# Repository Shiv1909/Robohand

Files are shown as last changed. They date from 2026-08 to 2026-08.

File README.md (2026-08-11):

# Robohand — DIY Fingerbot

A voice-controlled robot finger that physically presses a wall switch on command.
Say *"Hey Siri, turn on the fan"* and a servo swings an arm into the switch.

The homemade version of a commercial SwitchBot Bot — built as a first hands-on
robotics / embedded project, and aiming to beat the commercial one on a specific
axis: **density**. A SwitchBot is 43 × 37 mm and physically cannot fit two adjacent
switches on a 22 mm-pitch Indian modular board. An MG90S can.

**Coming back to this after a break? Start with [STATUS.md](STATUS.md)** — current
state, what's blocked, what to do next, and every decision already settled.

## Status

**"Hey Siri, turn on Fingerbot" swings the arm.** Working on real hardware as of
2026-08-11 — the firmware side is essentially done, and what's left is mechanical.

| Phase | State |
| --- | --- |
| 0 — Simulation | ✅ done (Arduino Uno, in Wokwi) |
| 1 — Servo moves on real hardware | ✅ **validated 2026-08-11** |
| 1b — Debounced button trigger | ✅ **validated 2026-08-11** — 14 pushes, 14 presses |
| 1c — Two-position on/off toggle | ✅ **validated 2026-08-11** — strict ON/OFF alternation |
| 1d — Serial calibration console | firmware written + compiling + unit-tested, **not yet flashed** |
| 2 — WiFi trigger | ⏭️ skipped — HomeSpan subsumes it |
| 3 — Siri / Apple Home | ✅ **validated 2026-08-11** — paired with Apple Home, Siri drives the servo |
| 4 — 3D-printed arm and mount | blocked on switch measurements |
| 5 — Permanent install | not started |

## Hardware

ESP32 + MG90S metal-gear servo, driven from a **separate 5 V supply** with a common
ground. Full parts list with links and prices: **[BOM.md](BOM.md)**.

## Quick start

```bash
# compile
pio run -e phase1_autopress          # servo presses every 3s, no inputs
pio run -e phase1b_button            # servo presses on a debounced button
pio run -e phase1c_toggle            # button toggles between on/off angles
pio run -e phase1d_calibrate         # serial console for finding the angles
pio run -e phase3_homekit            # Siri / Apple Home (needs include/secrets.h)

# run logic tests on your PC — no ESP32 needed (41 tests)
pio test -e native

# flash
pio run -e phase1_autopress -t upload
```

Always pass `-e`. A bare `pio run` builds only the default environment and silently
skips the other.

**Before wiring anything, read [WIRING.md](WIRING.md).** It has the layout and a
pre-flight checklist — reversed polarity on the servo supply will kill the ESP32.

## Repo layout

```
src/phase1_autopress.cpp    Phase 1 firmware. Known-good baseline; keep it working.
src/phase1b_button.cpp      Phase 1b firmware. Standalone by design.
src/phase1c_toggle.cpp      Phase 1c firmware. Two-position on/off with state.
src/phase1d_calibrate.cpp   Serial console for finding the angles. A tool.
src/phase3_homekit.cpp      Phase 3 firmware. HomeKit accessory driven by Siri.
include/debounce.h          Debounce logic, free of Arduino calls so it unit-tests.
include/switch_state.h      On/off state machine. Idempotent — see below.
include/command_parser.h    Console command parsing + range validation.
include/secrets.h.example   Template for WiFi credentials. Copy to secrets.h.
test/test_debounce/         8 native Unity tests for the debouncer.
test/test_switch_state/     13 native Unity tests for the state machine.
test/test_command_parser/   20 native Unity tests for the parser.
test/wokwi/                 Wokwi scenario (blocked — see project.md).
cad/fingerbot.scad          Parametric OpenSCAD source for the printed parts.
cad/render.ps1              Renders every part to cad/stl/.
cad/stl/                    Ready-to-slice STLs, regenerated by render.ps1.
platformio.ini              Six environments: five firmware, one native test.
project.md                  Plan, phase status, and every gotcha learned so far.
BOM.md                      Parts list, prices, power analysis, measurements.
WIRING.md                   Wiring diagram and first-power-on checklist.
CLAUDE.md                   Toolchain notes for this machine.
```

Each firmware environment compiles exactly one source file, so both can live in
`src/` without their `setup()`/`loop()` colliding. Phase 1 is preserved permanently
as a fallback for isolating hardware faults.

## Things learned the hard way

Full list in [project.md](project.md). The ones that cost the most time:

- **Servo brownout.** An MG90S stalling against a stiff switch browns out the ESP32
  through its onboard regulator. The board reboots at exactly the moment the finger
  pushes hardest — it looks like a code bug and isn't. Separate 5 V supply, common
  ground, bulk capacitor near the servo. *(Verified 2026-08-11: with that wiring,
  22 s of continuous pressing produced no resets.)*
- **No COM port at all ≠ nothing on serial.** The DevKitC's CP2102N needs a Silicon
  Labs driver that Windows Update does not carry. Until it's installed there is no
  port to select, which reads as a dead board. See `WIRING.md`.
- **A 4-pin tactile switch has only two circuits.** Half its leg pairs are
  permanently closed, and the two orientations look identical from outside. **Wire
  it diagonally** — diagonally opposite legs are always one from each pair, so it's
  correct whichever way the switch went in.
- **ESP32Servo needs its PWM timers allocated before `attach()`**, or the servo
  silently never moves.
- **Rockers need two press points.** Press the top for ON, the bottom for OFF. A
  single-point presser can only ever switch one way — solved with a push-pull tether,
  the same approach SwitchBot uses.
- **State changes must be idempotent.** Apple Home re-sends state freely. Actuating
  on a redundant "turn on" would physically press the switch again and turn the light
  *off*. `switch_state.h` returns `Action::None` in that case, and it's unit-tested.
  *(Confirmed in the wild 2026-08-11: HomeKit did exactly this within 100 seconds of
  first pairing, and the arm correctly refused to move.)*
- **Wokwi cannot simulate ESP32 here.** AVR works fine with the same CLI and token;
  ESP32 produces no serial and never executes. Ruled out across both the CLI and the
  VS Code extension. Probably why Phase 0 was done on an Uno.
- **Battery life is set by idle WiFi, not the servo.** The servo is under 2 % of the
  energy budget. Light sleep (not deep sleep) gets ~7.5 mA and makes portable viable.

## License

Personal project, no license granted. Ask if you want to reuse something.

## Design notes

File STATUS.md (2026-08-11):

# STATUS — read this first after a break

Snapshot of the whole project as of **2026-08-11**. Written as a handoff: if you
(or a fresh Claude session) come back cold, start here.

**Everything is committed and pushed** to `main` at
<https://github.com/Shiv1909/Robohand>. Bench photos on the laptop are untracked
and not needed.

---

## Where we are in one line

**Siri works.** "Hey Siri, turn on Fingerbot" swings the arm. Phases 1, 1b, 1c and
**3** are all validated on real hardware (2026-08-11).

The electronics and firmware side of this project is essentially done. What remains
is mechanical: printing an arm, mounting it, and calibrating the angles against the
real switchboard.

| Phase | State |
| --- | --- |
| 0 — Wokwi simulation | ✅ done, on an Arduino Uno |
| 1 — Servo moves | ✅ **validated on hardware 2026-08-11** |
| 1b — Debounced button | ✅ **validated on hardware 2026-08-11**, real switch |
| 1c — Two-position on/off | ✅ **validated on hardware 2026-08-11** |
| 1d — Calibration console | firmware ✅ · 20 tests ✅ · **not flashed** |
| 2 — WiFi trigger | ⏭️ **skipped** — HomeSpan subsumes it |
| 3 — Siri / HomeSpan | ✅ **validated on hardware 2026-08-11** |
| 4 — Printed parts | CAD ✅ rendering · **not printed, not test-fitted** |
| 5 — Permanent install | not started |

**41 native tests pass. 4 firmware environments build clean.**

---

## What the first hardware session actually proved (2026-08-11)

Measured, not assumed:

- **No brownout.** 22 s of continuous auto-pressing, six cycles, and the boot
  banner never reappeared. The 5 V 2 A adapter + 1000 µF near the servo is
  sufficient for one MG90S. This was the project's single biggest risk.
- **Timing is exact.** 0.8 s hold, 3.0 s gap, 3.8 s period — matches
  `phase1_autopress.cpp` to the tenth of a second.
- **The debouncer works against real bounce.** Two separate runs: eight jumper taps
  on GPIO 4 gave eight presses, and fourteen pushes of the real tactile switch gave
  fourteen presses. **No two events closer than 0.9 s in either run** — contact
  bounce settles in single-digit milliseconds, so zero double-fires got through.
  `include/debounce.h` needs no tuning; `DEBOUNCE_MS = 50` is right.
- **The two-position state machine alternates correctly.** Eight presses under
  `phase1c_toggle` gave strict ON/OFF/ON/OFF with no repeats, each move taking
  exactly 0.7 s (`HOLD_MS` 500 + 200 ms settle). `include/switch_state.h` behaves on
  hardware as its 13 tests said it would.
- **The idempotency guard fired for real, within 100 s of the first Siri session.**
  HomeKit sent "turn on" while the switch was already ON, and `requestOn()` returned
  `Action::None` so the arm did not move. With a plain bool it would have pressed an
  already-on rocker and turned the light OFF. This is the single most valuable thing
  `include/switch_state.h` does, it was predicted in that file's header comment
  before any hardware existed, and it is now observed rather than theoretical.
- **Siri and the physical button coexist, sharing one source of truth.** Serial
  caught the sequence that proves it: HomeKit turned the switch ON, then a button
  press turned it **OFF** rather than ON — so `toggle()` read the state Siri had
  set. The button also calls `setVal()` to push its new state up to HomeKit, so
  Apple Home doesn't go stale and the next Siri command isn't silently swallowed.
- **3.3 V PWM drives the MG90S fine.** The logic level converter (item 16919) was
  bought as insurance and is not needed.
- **HomeSpan must be pinned to 1.9.x.** HomeSpan 2.x hard-`#error`s unless the
  arduino-esp32 core is ≥ 3.3.0, and `platform = espressif32 @ 7.0.1` ships 2.0.17.
  Pinned in `platformio.ini`, scoped to the Phase 3 env only — see below.
- **Wire tactile switches diagonally.** Straight across a row gave a permanent
  closed circuit; the same switch worked immediately when rewired diagonally. See
  `WIRING.md` — this cost an hour.

---

## What's actually blocked

1. **Switch measurements not taken.** Blocks final arm length and mount position.
2. **Wokwi can't simulate ESP32** here. Dead end — don't retry, see below.

Nothing else. Phases 1 and 1b are done on hardware.

---

## Next actions, in order

Do these in sequence. Each adds exactly one new thing to debug.

**Everything left is mechanical.** No firmware is blocked.

1. **Measure the switchboard** — rocker height × width, gang pitch, throw. Needs
   only a ruler, and it is the main blocker: it decides arm length and mount
   position for Phase 4.
2. **Print `arm20.stl` in PETG.** Smallest, fastest print, and it tests the least
   certain dimensions in the design — the `horn_*` values are datasheet guesses for
   the stock plastic horn. If they're wrong the arm won't mount at all, so find out
   in 15 minutes rather than after an hour on the cradle. Print it flat, as
   oriented: the bending load then runs *within* the layers rather than across
   them, and it needs no supports.
3. Then `cradle.stl`, also PETG. Test-fit both against the real servo, correct the
   parameter block in `cad/fingerbot.scad`, and re-run `cad\render.ps1`.
4. Mount it on the switchboard with the push-pull tether (see `project.md`, "The
   rocker problem").
5. `pio run -e phase1d_calibrate -t upload` → find the three angles by typing,
   `save`, then paste them into **both** `phase1c_toggle.cpp` and
   `phase3_homekit.cpp`. Needs the printed arm and a real mount first.
6. Then scale: servos 2..N for the other switches on the board.

The angles in `phase1c_toggle.cpp` and `phase3_homekit.cpp` (REST 90, ON 60,
OFF 120) are placeholders. They are *not* calibrated against anything — step 5's
job. Both files carry the same three constants; keep them in step.

---

## Toolchain installed on this machine

All PATH entries are in the **User** environment, so they survive a restart. Open
a **new** terminal after rebooting — and restart VS Code fully, not just its
integrated terminal, since it inherits the PATH of whatever launched it.

| Tool | Version | Location / notes |
| --- | --- | --- |
| PlatformIO Core | 6.1.19 | `~\.platformio`, `penv\Scripts` on User PATH |
| MinGW-w64 GCC | 16.1.0 | winget WinLibs UCRT, on User PATH. **Required for `pio test`** |
| OpenSCAD | 2021.01 | `C:\Program Files\OpenSCAD` — *not* on PATH; `render.ps1` finds it |
| wokwi-cli | 0.26.1 | `%LOCALAPPDATA%\Programs\wokwi-cli`, on User PATH |
| Node / npm | 24.14.0 / 11.9.0 | |
| gh | 2.95.0 | authenticated as `Shiv1909` |
| CP210x VCP driver | Silicon Labs | installed 2026-08-11, `oem186.inf`. **Windows Update does not have it** |

### The ESP32 shows up as COM3

The DevKitC-32E uses a **CP2102N** USB-UART bridge. Windows 11 has no driver for
it and Windows Update will not find one — Device Manager reports
`CM_PROB_FAILED_INSTALL` (Code 28) and **no COM port appears at all**, so
`pio device list` is silently empty. The board is fine; it's just unreachable.

Fixed by installing the Silicon Labs CP210x Universal Windows Driver
(`silabser.inf`) with `pnputil /add-driver ... /install` from an elevated shell.
Already done on this machine; only relevant if it's ever rebuilt.

**Build output lives outside this folder** — `workspace_dir` in `platformio.ini`
sends `.pio` to `%LOCALAPPDATA%\pio-workspace\fingerbot`, because this project
sits in a OneDrive-synced tree. If a `.pio\` folder ever appears next to `src\`,
that redirect got lost.

### Two machine-specific traps

- **Never run `python get-platformio.py`.** Bare `python` here resolves to another
  app's virtualenv (`AppData\Local\hermes\hermes-agent\venv`). Use `py -3.13`.
- **Set a short TEMP before running pio from an agent session.** The scratchpad
  path is ~150 chars and pip/pio blow past Windows' 260-char `MAX_PATH`. The error
  blames antivirus; that's a red herring.
  ```powershell
  $env:TMP = "$env:LOCALAPPDATA\Temp"; $env:TEMP = $env:TMP
  ```

`WOKWI_CLI_TOKEN` is stored in the User environment. **The repo is public — never
commit it.** Remove with:
```powershell
[Environment]::SetEnvironmentVariable("WOKWI_CLI_TOKEN", $null, "User")
```

---

## Decisions already made — don't re-litigate

Each of these cost real time to work out. Full reasoning is in `project.md`.

| Decision | Why |
| --- | --- |
| **Separate 5 V supply, common ground, 1000 µF near the servo** | Stall current browns out the ESP32. Board reboots exactly when the arm pushes hardest — looks like a code bug, isn't |
| **`ESP32PWM::allocateTimer()` before `attach()`** | Otherwise the servo silently never moves |
| **Phase 1 kept as a permanent baseline** | Flash it to prove servo+wiring+power still work before debugging anything else |
| **Phase 2 skipped** | HomeSpan gives phone control *and* Siri from the same code |
| **Phase 3 deferred until 1/1b run on hardware** | One new variable per flash. HomeSpan first would give a dead servo six possible causes instead of one |
| **Rocker needs two press points** | Top = ON, bottom = OFF. Solved with a push-pull tether to an adhesive tab, as SwitchBot does |
| **State changes must be idempotent** | Apple Home re-sends state; acting on a redundant "turn on" would physically turn the light off |
| **Arm 20–25 mm, not 40** | SwitchBot's 8 N target ÷ MG90S's 19.6 N·cm. A 40 mm arm gives only 4.9 N |
| **Wokwi ESP32 is dead here** | AVR works with the same CLI and token; ESP32 never executes. Both CLI and VS Code extension. Probably why Phase 0 used an Uno |
| **Portable IS viable** | ~7.5 mA with WiFi light sleep, not the 80 mA default. ~2 weeks per 18650. Idle radio dominates; the servo is <2 % |
| **6 servos need staggered mounting** | Cradle is 28.1 mm wide, gang pitch ~22 mm. Alternate above/below the rocker line |
| **Don't buy a small board yet** | ESP32-C3 has only 6 PWM channels; Thread would need a C6. A PCA9685 makes the board choice irrelevant |

---

## Open questions for you

- [x] ~~**Is your filament PETG or PLA?**~~ **Both available. Use PETG throughout**
      (decided 2026-08-11), including the throwaway test-fit prints.

      An earlier version of this file said PLA for test-fitting and PETG for the
      final parts. **That was wrong.** PETG prints 0.1–0.3 mm larger than PLA at the
      same nominal size — the same order as the tolerances being checked
      (`horn_blade_t` is 1.9 mm, `horn_hub_d` is 7.4 mm). A PLA fit therefore does
      not predict a PETG fit, so the test would have to be repeated anyway.

      Printing the throwaway part in PETG also means the **PETG printer profile gets
      debugged on a part nobody cares about** — stringing, ooze and bed adhesion are
      problems you have to solve for the real parts regardless.

      PLA is still fine for a pure "does this geometry make sense" sanity check, but
      **any dimension you intend to trust must be measured in PETG.**
- [ ] **Rocker dimensions with a ruler.** The AR measurement said 2 × 7 cm, but the
      photos show a ~1:2 ratio, so the height is probably ~4–4.5 cm.
- [ ] **Gang pitch**, centre-to-centre. Decides how bad the staggering has to be.
- [ ] **Actuation force** (optional — see `BOM.md` for three ways to measure it
      without a proper scale). Not a blocker; printing 20/25/30 mm arms settles it.

---

## Offered but not built

- **CI on GitHub Actions** — would run the 41 tests + 4 builds on every push.
- **Electronics enclosure** — the ESP32 box; DevKitC is 54.4 × 27.9 × 13 mm.
- **A phone app** — recommended against. Apple Home *is* the app.

---

## Document index

| File | What's in it |
| --- | --- |
| `README.md` | Project overview, quick start, repo layout |
| `project.md` | The plan, phase status, every gotcha learned |
| `BOM.md` | Parts list with Robu links, power analysis, measurements |
| `WIRING.md` | Wiring diagram + first-power-on checklist. **Read before connecting anything** |
| `CLAUDE.md` | Toolchain notes for this machine |
| `STATUS.md` | This file |

### Commands worth remembering

```bash
pio run -e phase1_autopress -t upload    # always pass -e; bare `pio run` skips envs
pio test -e native                       # 41 tests, no hardware needed
cd cad; .\render.ps1                     # regenerate STLs + previews
```

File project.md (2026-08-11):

# DIY Fingerbot — Project Brief

A voice-controlled robot finger that presses a physical wall switch on command
("Hey Siri, turn on the fan"). This is the DIY version of a commercial Fingerbot /
SwitchBot Bot, built as a first hands-on robotics + embedded/IoT project.

If you're Claude Code reading this: this file is the handoff from a planning chat.
It has the full plan and current status so you can pick up mid-project.

## What we're building

An ESP32 drives a small servo motor. The servo has a 3D-printed arm that swings to
press a switch, holds briefly, then retracts. The ESP32 announces itself to Apple
Home (via the HomeSpan library) so Siri can trigger the press — no hub, no
subscription.

## Hardware

Full shopping list with specs, reasoning, and what NOT to buy: **[BOM.md](BOM.md)**.
That file also lists the switch measurements needed before Phase 4.

**Wiring layout and the first-power-on checklist: [WIRING.md](WIRING.md).** Read it
before connecting anything — reversed polarity on the servo supply kills the ESP32.

- **ESP32 dev board** (WiFi + BLE — needed for the Siri/HomeKit step)
- **MG90S servo** (metal-gear; wall switches need a firm push and metal gears last)
- **Separate 5V supply for the servo** (see SERVO BROWNOUT below — not optional)
- Pushbutton (Phase 1b trigger)
- Breadboard + jumper wires
- USB cable to match the board
- 3D-printed arm + housing (Phase 4 — a printer is available)

## Target

A rectangular multi-gang wall switchboard with several switches. End goal is to
voice-control specific switches on it. **We start with ONE switch, all the way
through Siri, then replicate.** One ESP32 can drive several servos, each exposed to
Apple Home as its own named accessory — so one brain controls the whole board.

## The rocker problem (found 2026-08-04, from photos of the actual board)

The target is a **6-gang rocker switchboard**, and rockers are not buttons. You
press the **top** for ON and the **bottom** for OFF. They pivot in the middle, so
pressing the centre does nothing at all.

**A single arm that presses one spot can therefore only ever switch one way.** As
currently written, the firmware would turn a light on and then be unable to turn it
off. This is the same constraint that makes a commercial SwitchBot need its
stick-on lever accessory.

### Solution: push-pull with a tether (how SwitchBot does it)

An earlier draft of this section proposed a centre-pivot arm sweeping up and down
to hit both halves. **That was wrong for this board** — it needs clearance *beside*
the rocker, and on a 6-gang plate the modules abut each other, so there is none.

SwitchBot solves it vertically instead, and the same approach fits here. Mount the
servo **below** the switch. Stick a small **adhesive tab onto the rocker face** and
run a short tether from the arm to that tab. Now one contact point does both jobs:

```
   ┌─────────┐
   │  upper  │
   │ - - - - │   <- rocker pivot
   │ [tab]   │   <- adhesive tab + tether
   └────┬────┘
        │  arm rotates one way  -> PUSHES tab in   -> state B
   ●════╯  arm rotates other way -> PULLS tab out  -> state A
   servo below the plate
```

Pulling the lower half outward rocks the switch exactly as pressing the upper half
would — so a single point, pushed and pulled, covers both directions.

Trade-off: it requires sticking something to the switch, which the sweep design
avoided. That is the price of working on a multi-gang plate, and the commercial
product pays it too.

### What this changes

- **Phase 4 (mechanical):** the mount must be centred vertically on the rocker, not
  offset above or below it. Arm length must clear both halves without fouling the
  plate. This constrains the design far more than a simple press would.
- **Phase 3 (firmware):** the accessory is a **stateful switch, not a momentary
  press**. `PRESS_ANGLE` becomes two angles — `ON_ANGLE` and `OFF_ANGLE` — with a
  neutral rest between them, and the ESP32 must track which state it last set.
- **Known limitation:** the ESP32 cannot tell whether someone flipped the switch by
  hand, so its idea of the state can drift out of sync with reality. Options are to
  accept it, or add a sensor later. Worth deciding before Phase 3, not after.

Phase 1/1b firmware is unaffected — it only ever needed to prove motion.

### Benchmarks from the commercial SwitchBot Bot

Useful design targets, from their published spec:

| Spec | SwitchBot Bot | Implication for us |
| --- | --- | --- |
| Press force | **8 N** (1.15 kgf) | our force target |
| Arm stroke | 12 mm | rocker throw is small; sweep can be modest |
| Movement angle | 120° | well inside the MG90S range |
| Size | 43 × 37 × 24 mm | **wider than a 22 mm module — see below** |
| Battery | CR2 3 V, 600 days @ 2/day | ≈ 55 µA average. Only possible over BLE |
| Radio | Bluetooth 4.2, hub for Siri | not WiFi — deliberately |

**Arm length falls straight out of the 8 N target.** The MG90S gives 2.0 kg·cm at
6 V ≈ 19.6 N·cm, so force at the tip is `19.6 / r` newtons with `r` in cm:

| Arm length | Force at tip @ 6 V | @ 4.8 V (1.8 kg·cm) |
| --- | --- | --- |
| 2.0 cm | 9.8 N | 8.8 N |
| **2.5 cm** | **7.8 N** | 7.1 N |
| 3.0 cm | 6.5 N | 5.9 N |
| 4.0 cm | 4.9 N | 4.4 N |

So **keep the arm at 2–2.5 cm** to match SwitchBot's force. The earlier ~4 cm
estimate in this project was too generous. The MG90S is adequate — but only with a
short arm, which makes the actuation-force measurement the thing that decides
whether this works at all.

**Two things their spec quietly confirms:**

1. **600 days on a CR2 is ~55 µA average.** No WiFi device reaches that; our
   light-sleep ESP32 at ~7.5 mA is over 100× worse. This is hard evidence for the
   Thread/BLE point in `BOM.md` — battery life on WiFi is a physics problem, not a
   tuning problem.
2. **At 43 × 37 mm, a SwitchBot cannot fit two adjacent modules on a 22 mm pitch.**
   The commercial product physically cannot automate this 6-gang board densely.
   An MG90S body is 22.8 × 12.2 mm, so mounted with the narrow dimension
   horizontal it *can* sit at ~22 mm pitch. The DIY build can beat the commercial
   one on density here — which is a genuinely good reason for this project to exist.

## Phased plan

- [x] **Phase 0 — Simulation.** Press logic proven in Wokwi.
- [x] **Phase 1 — Real circuit.** ESP32 + servo on a breadboard, servo physically
      swinging from firmware over USB.
  - [x] Firmware written and compiling — `src/phase1_autopress.cpp`
  - [x] Flashed and validated on real hardware — **2026-08-11**, no brownout
- [x] **Phase 1b — Button trigger.** Pushbutton on a GPIO fires the press instead
      of the auto-loop.
  - [x] Firmware written and compiling — `src/phase1b_button.cpp`
  - [x] Flashed and validated on real hardware — **2026-08-11**, real tactile
        switch on GPIO 4: 14 pushes, 14 presses, no double-fires
- [x] **Phase 1c — Two-position toggle.** Separate ON and OFF angles with state
      tracking, because a rocker has two press points. Same wiring as 1b.
  - [x] Firmware written and compiling — `src/phase1c_toggle.cpp`
  - [x] State machine unit-tested — `include/switch_state.h`, 13 tests
  - [x] Flashed and validated on real hardware — **2026-08-11**, 8 presses gave
        strict ON/OFF/ON/OFF alternation, 0.7 s per move
  - [ ] Angles calibrated against the real switch ← needs Phase 4 mount + Phase 1d
- [ ] **Phase 1d — Calibration console.** Serial commands to find the three
      angles without a reflash per guess. A tool, not part of the product.
  - [x] Firmware written and compiling — `src/phase1d_calibrate.cpp`
  - [x] Command parser unit-tested — `include/command_parser.h`, 20 tests
  - [ ] Used against the real switch
- [ ] ~~**Phase 2 — Wireless trigger.**~~ **SKIPPED.** HomeSpan in Phase 3 subsumes
      it — a native HomeKit accessory already gives phone control *and* Siri from
      the same code, so a standalone web trigger is throwaway work.
- [x] **Phase 3 — Siri / Apple Home.** HomeSpan makes the ESP32 a native HomeKit
      accessory; "Hey Siri, turn on X" fires the servo.
  - [x] Firmware written and compiling — `src/phase3_homekit.cpp`
  - [x] Paired with Apple Home and driven by Siri on real hardware —
        **2026-08-11**. The hold until 1/1b were validated worked exactly as
        intended: WiFi and pairing were the only new variables left to debug.
  - [x] **Idempotency guard confirmed in the wild** — HomeKit re-sent "turn on"
        while already ON and the arm correctly did not move
  - [x] **Physical button works alongside Siri** — 2026-08-11. Both paths share
        one `SwitchState`, and the button pushes its new state up to HomeKit with
        `setVal()` so Apple Home never goes stale
  - [ ] Angles calibrated against the real switch ← needs Phase 4 mount + Phase 1d
- [ ] **Phase 4 — Mechanical body.** Design + 3D-print the arm and a mount sized to
      the actual switchboard; calibrate press angle/depth.
  - [x] Parametric CAD written and rendering — `cad/fingerbot.scad`
  - [ ] Test-fitted against the real servo ← **dimensions are from datasheets**
  - [ ] Arm length chosen against the real switch
- [ ] **Phase 5 — Permanent.** Battery power, enclosure, mount on the wall.
- [ ] **Later — Scale.** Add servos 2..N for the other switches on the board.

## Current status

**Siri works.** "Hey Siri, turn on Fingerbot" swings the arm (2026-08-11). Phases 1,
1b, 1c and 3 are all validated on real hardware, and the firmware side of this
project is essentially complete. Everything remaining is mechanical: print an arm,
mount it on the switchboard, calibrate the angles.

The Phase 3 session also produced the project's most satisfying result. Within 100
seconds of first pairing, HomeKit re-sent "turn on" while the switch was already ON,
and `SwitchState::requestOn()` returned `Action::None` so the arm did not move. That
is precisely the failure the class was built to prevent — with a plain bool it would
have pressed an already-on rocker and turned the light off. Predicted in a header
comment before any hardware existed; observed on the first try.

The servo presses on a 3 s timer under `phase1_autopress`, on a GPIO 4 trigger
under `phase1b_button`, and alternates between two angles with state tracking under
`phase1c_toggle` — eight presses gave strict ON/OFF/ON/OFF with no repeats, so
`include/switch_state.h` behaves on hardware exactly as its 13 tests said. Serial timing matches the firmware to the tenth of a second
(0.8 s hold, 3.0 s gap), and **the boot banner never reappeared across 22 s of
continuous pressing** — so the separate 5 V supply and the 1000 µF bulk cap are
doing their job, and the servo brownout this whole design was built around is not
occurring. That was the project's single biggest unknown and it is now closed.

The debouncer was tested twice — 8 jumper taps, then 14 pushes of the real tactile
switch — and produced exactly one press per input both times. No two events landed
closer than 0.9 s apart, and contact bounce settles within single-digit
milliseconds, so nothing spurious survived. `DEBOUNCE_MS = 50` needs no tuning.

Three things learned that cost real time — all now written up in `WIRING.md`: the
ESP32 needs a **CP2102N driver Windows Update does not carry** (no COM port appears
at all until it's installed); a 4-pin tactile switch has **only two circuits**, so
half its leg pairs are permanently closed; and the fix for that is to **wire the
switch diagonally**, which is correct regardless of orientation.

Toolchain: VS Code + PlatformIO Core 6.1.19 + Claude Code. PlatformIO Core is
installed at `~/.platformio` with `pio` on the user PATH.

## Firmware layout

Two PlatformIO environments, one source file each, so both phases stay
independently flashable:

| Environment | Source file | What it does |
| --- | --- | --- |
| `phase1_autopress` | `phase1_autopress.cpp` | Presses every 3s. No inputs. |
| `phase1b_button` | `phase1b_button.cpp` | Presses on a debounced button.  |
| `native` | `test/test_debounce/` | Debounce unit tests, on the PC. |

```
pio run -e phase1_autopress -t upload
pio run -e phase1b_button   -t upload
```

Always pass `-e`. A bare `pio run` builds only `default_envs` (`phase1_autopress`),
not both — so it will silently skip Phase 1b and look like it succeeded.

## Tests

```
pio test -e native
```

Eight Unity tests over `include/debounce.h`, running on the PC — no ESP32, no
servo, no wiring. Debounce is the only nontrivial algorithm in Phase 1b and the
one most annoying to diagnose on real hardware, so it's pinned down here with a
synthetic clock instead: clean press, bouncing contacts, held button, release,
double press, sub-window glitch, and `millis()` rollover at ~49 days.

The suite is verified non-vacuous — deleting the debounce window from
`Debouncer::update()` makes the glitch and bounce tests fail.

This is why the debounce logic sits in `include/debounce.h` rather than inline in
`phase1b_button.cpp`: it's free of `digitalRead()`/`millis()` so it compiles for
the host. `phase1b_button.cpp` just converts the active-low pin into a bool and
supplies `millis()`.

**Tests prove the logic, not the machine.** A green run says nothing about servo
torque, brownout, or wiring — those need hardware.

## Simulation (Wokwi) — set up, but BLOCKED

```
pio run -e phase1b_button
wokwi-cli . --scenario test/wokwi/phase1b_button.scenario.yaml --timeout 30000
```

`diagram.json` models the ESP32 + servo + pushbutton and passes `wokwi-cli lint`.
The button has bounce enabled, so the simulated firmware would face genuinely
dirty edges — a real integration test of the debouncer, covering what the unit
tests can't (ESP32Servo timer allocation, `attach()`, the GPIO pull-up).

**It does not run.** ESP32 simulations produce no serial and never execute. The
cause is outside this repo — full elimination trail is in `wokwi.toml`, but in
short: the token is valid, an AVR sketch simulates correctly with the same CLI
and token, and a bare `Serial.println` ESP32 sketch is equally silent. Flash
format, board type, and timeout were all ruled out.

**The VS Code extension fails the same way** (2026-08-02): simulator starts, the
servo never moves, serial stays empty. So this is not a wokwi-cli bug — both
front ends hit it, and the common factor is ESP32 itself.

**AVR works, ESP32 does not.** This is almost certainly why Phase 0 was proven on
an Arduino Uno rather than an ESP32 — the same wall, hit earlier. Worth
remembering before anyone sinks time into "simulate it first" again.

The decisive test not yet run: open an ESP32 project on wokwi.com in a browser.
Wokwi compiles server-side there, so it bypasses this machine's firmware
entirely. If that works, the problem is local; if it fails too, ESP32 simulation
simply isn't available here and the answer is to stop trying and wait for
hardware.

Treat this as unproven — the setup can currently only fail, never pass.

`phase1_autopress` is the default env and **the known-good baseline** — keep it
working. When a later phase misbehaves, flash it to prove the servo, wiring, and
power are still fine before debugging anything else. The two files duplicate their
servo code on purpose; sharing a header would mean a bug hunt in one phase could
silently change the baseline you fall back to.

## Why incremental (don't jump to HomeSpan)

Each flash should add exactly ONE new thing to debug:

> servo motion (Phase 1) → GPIO input (Phase 1b) → networking/pairing (Phase 3)

If the first flash were HomeSpan, a servo that doesn't move would have six possible
causes — wiring, power, the timer fix, WiFi credentials, HomeKit pairing, accessory
code — instead of one. HomeSpan is also best written when it can be flashed and
tested live, so WiFi and pairing bugs get caught in the moment rather than sitting
in week-old code.

## Key decisions & gotchas (learned the hard way)

- **SERVO BROWNOUT — wire around this from day one.** An MG90S stalling against a
  stiff wall switch pulls a current spike big enough to dip the voltage through the
  ESP32 dev board's onboard regulator and *reset the board mid-press*.
  **Symptom:** the ESP32 reboots at exactly the moment the finger pushes hardest.
  It looks like a code bug. It is not a code bug — no amount of firmware debugging
  will fix it.
  **Fix:** power the servo from a **separate 5V supply**, and tie the grounds
  together (ESP32 GND ↔ supply GND — common ground, required, or the servo won't
  see a valid signal). Do NOT run the servo off the ESP32's 5V/VIN pin. Wire it
  this way from the start rather than "fixing" it later.

- **Build output lives outside this folder, on purpose.** This project sits in a
  OneDrive-synced tree. `workspace_dir` in `platformio.ini` redirects the whole
  `.pio` workspace to `%LOCALAPPDATA%\pio-workspace\fingerbot` (~50 MB and growing)
  so OneDrive isn't syncing build artifacts or locking files mid-compile. If you
  ever see a `.pio` folder appear next to `src/`, that redirect got lost.

- **Use ESP32, not Arduino Uno, for the real build** — the Uno was only used to
  prove the mechanism in simulation. The real build needs WiFi/BLE for Siri.

- **ESP32Servo needs its PWM timers allocated BEFORE `attach()`** or the servo
  silently never moves. The `ESP32PWM::allocateTimer(...)` lines in both firmware
  files are that fix — keep them.

- **Avoid ESP32 strapping pins for inputs** (GPIO 0, 2, 12, 15) — they're read at
  boot and a held button can stop the board from starting. The Phase 1b button is
  on GPIO 4.

- Build ONE switch end-to-end before scaling to the multi-gang board.

- **Wokwi CLI cannot currently simulate ESP32** on this setup — see "Simulation"
  above. AVR simulates fine with the same CLI and token, so the tooling and
  account are good; it's ESP32-specific. (This supersedes the older note here
  that Wokwi "isn't needed" — that was written assuming hardware was days away.
  With hardware delayed, simulating the real compiled binary is worth having;
  it just doesn't work yet.)

## Next actions

Done already: PlatformIO Core installed, ESP32 toolchain + ESP32Servo pulled, and
both environments compiled clean.

1. Install the PlatformIO **extension** in VS Code — the CLI is already installed;
   the extension just adds the toolbar and environment switcher.
2. When the ESP32 arrives: wire the servo to its **own 5V supply with common
   ground**, then `pio run -e phase1_autopress -t upload` and watch the arm press
   every 3s.
3. Then add the button on GPIO 4 and `pio run -e phase1b_button -t upload`.
4. Only once both are validated on real hardware, write Phase 3 (HomeSpan).

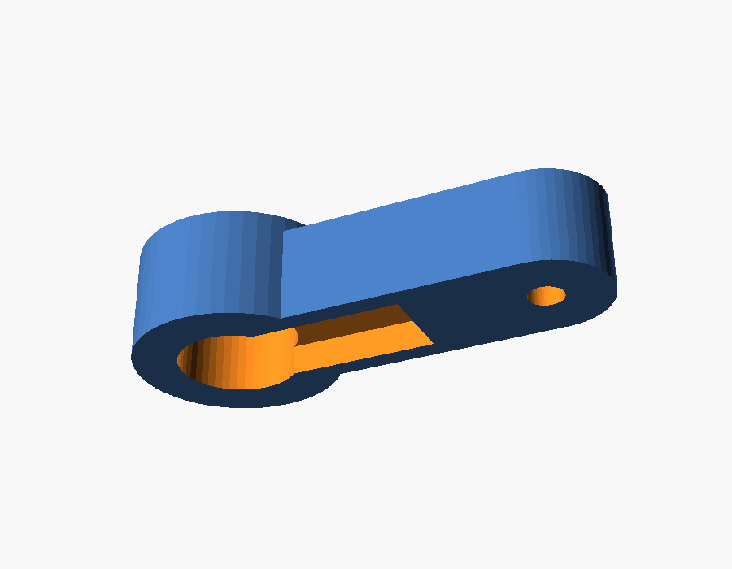
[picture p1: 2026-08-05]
cad/preview/arm_underside.png

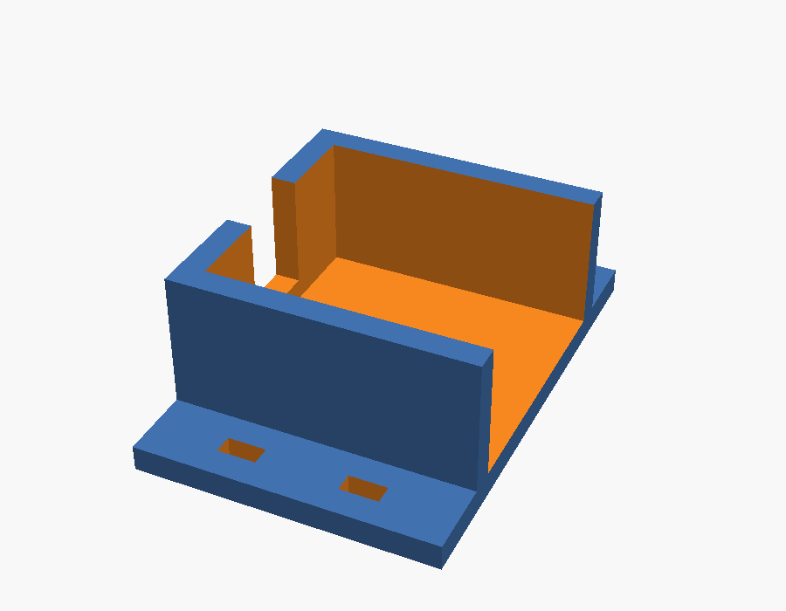
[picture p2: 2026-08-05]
cad/preview/cradle.png

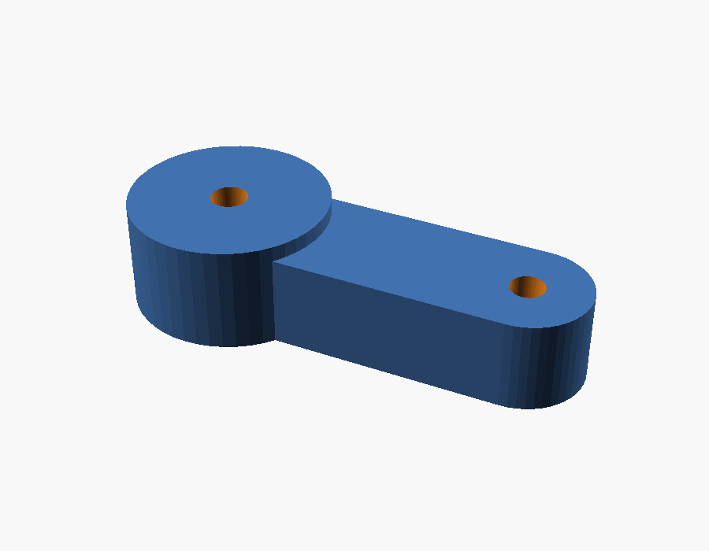
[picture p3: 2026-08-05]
cad/preview/arm.png

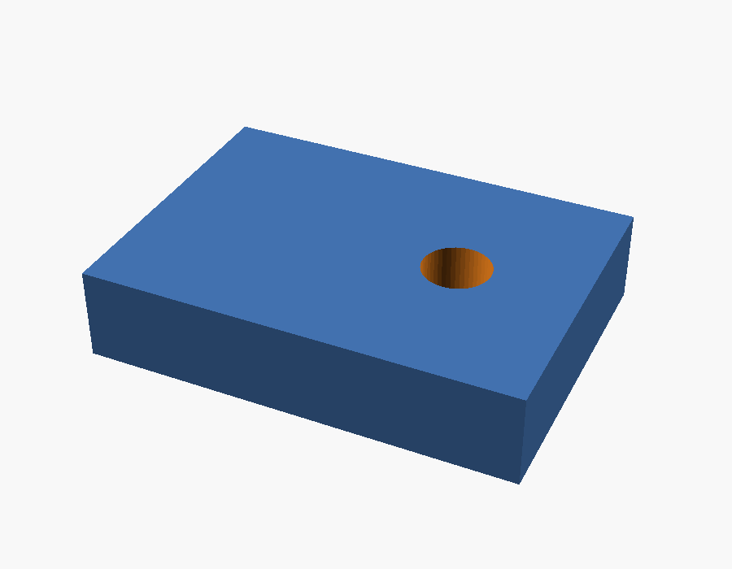
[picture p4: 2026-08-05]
cad/preview/tab.png

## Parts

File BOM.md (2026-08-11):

# Bill of Materials — DIY Fingerbot

Single consolidated order from **[Robu.in](https://robu.in/)** — everything below is
in stock there, so it ships as one parcel with one delivery. Robu ships free above
₹500, so shipping is effectively ₹0 on this order.

> **Prices are estimates (₹, Aug 2026).** Only the MG90S (₹239) and the capacitors
> were confirmed on vendor pages; the rest are typical current street prices.
> Treat totals as a budget, not a quote.

---

## ORDER THIS NOW

Everything needed to build and finish **Phase 1 + Phase 1b**. Nothing here is
speculative; nothing for Phase 4/5 is included.

Tick these off as you order / as they arrive.

**Core — skip any already ordered**

- [ ] **1. ESP32 DevKit, 38-pin** — ₹500 —
      [Robu](https://robu.in/product/esp32-38pin-development-board-wifibluetooth-ultra-low-power-consumption-dual-core/)
- [ ] **2. MG90S servo — must say 180°** — ₹239 —
      [Robu](https://robu.in/product/towerpro-mg90s-mini-digital-servo-motor-180-rotation-standard-quality/)
- [ ] **3. Breadboard, 830 points** — ₹110 —
      [Robu](https://robu.in/product/transparent-830-points-solderless-breadboard/)
- [ ] **4. Jumper wires, M-M + M-F** (2 sets) — ₹160 —
      [Robu](https://robu.in/product-category/dupont-cable/)

**Power + brownout fix + Phase 1b**

- [ ] **5. 5 V 3 A adapter**, 5.5×2.1 mm — ₹350 —
      [Robu](https://robu.in/product/orange-5v-3a-power-supply-adapter-charger-with-5-5mm-dc-plug/)
- [ ] **6. DC jack, female with wires** — ₹40 —
      [Robu](https://robu.in/product/dc-jack-connector-female-2-1mm-x-5-5mm-with-wire/)
- [ ] **7. 1000 µF 16 V leaded ×3** — ₹45 —
      [Robu](https://robu.in/product/16zlh1000mhfc10x16-rubycon-1000uf-16v-%C2%B120-plugind10xl16mm-aluminum-electrolytic-capacitors-leaded-rohs/)
- [ ] **8. Ceramic capacitor kit** — ₹150 —
      [Robu](https://robu.in/product/ceramic-capacitor-assorted-kit-30-kinds-from-2pf-0-1uf/)
- [ ] **9. Tactile pushbuttons ×20** — ₹75 —
      [Robu](https://robu.in/product/6x6x5mm-tactile-push-button-switch-pack-of-20/)

**Tools — not parts; droppable to save ₹510**

- [ ] **10. Multimeter (MAS830L)** — ₹450 —
      [Robu](https://robu.in/product/haoyue-mas830l-digital-handheld-multimeter-600-vac-dc/)
- [ ] **11. Logic level converter, 4-ch** — ₹60 —
      [Robu](https://robu.in/product/level-converter-4-channel/)

### If something is out of stock — verified alternates

**ESP32 DevKit**

- [Espressif ESP32-DevKitC-32E](https://robu.in/product/espressif-esp32-devkitc-esp32-wroom-3-2e-development-board/) — official Espressif, PCB antenna
- [ESP32-WROVER-E DevKitC](https://robu.in/product/esp32-wroom-e-esp32-devkitc-core-board-for-arduino/) — adds PSRAM, harmless here

> ⚠️ **Avoid the "U" and "UE" variants** (ESP32-WROOM-32**U**, 32**UE**). Those have
> a u.FL connector *instead of* a PCB antenna — no antenna in the box, so WiFi
> effectively won't work until you buy one. Easy to order by mistake; the listings
> look almost identical.

**MG90S servo**

- [MG90S 9g Servo Metal Gear](https://robu.in/product/mg90s-9g-servo-metal-gear/)
- [TowardPro MG90S 180°](https://robu.in/product/towardpro-mg90s-mini-digital-servo-2-2kg-0-08sec-13g/)
- [ACEBOTT MG90 180°](https://robu.in/product/acebott-mg90-metal-gear-micro-servo-motor-180-degrees-compatible-with-esp32-arduino/)

> ⚠️ Never the **360° continuous rotation** version — it cannot hold an angle.

**Breadboard**

- [MB102 830 points](https://robu.in/product/mb102-830-points-solderless-prototype-pcb-breadboard-high-quality/)
- [ZY-201 830 points](https://robu.in/product/zy-201-830-points-solderless-breadboard/)

**5 V adapter**

- [Orange 5V 3A, BIS approved](https://robu.in/product/orange-5v-3a-power-adapter-with-dc-plug-bis-approved)
- [Orange 5V 2A, dual pin DC](https://robu.in/product/orange-5v-2a-power-supply-with-dual-pin-dc-plug-adapter/) — 2 A is
  fine for one servo; only limits you when scaling to several

> ⚠️ **The plug must be 5.5 × 2.1 mm.** Robu also stocks a
> [Pro-Range 5V 3A with a 5.5 × **2.5** mm plug](https://robu.in/product/pro-range-5v-3a-power-adapter/) —
> that will not seat properly in the 2.1 mm pigtail jack (item 6) and gives an
> intermittent connection, which looks exactly like a brownout. Do not mix sizes.

### **Total: ₹2,179** — shipping free (Robu, above ₹500)

**Skip items 1–4 if already ordered → ₹1,170.**
**Skip 10–11 as well → ₹660 absolute minimum.**

Three checks before paying:

1. **MG90S must say "180° Rotation".** The 360° continuous-rotation version cannot
   hold an angle and would be useless — see the warning below.
2. **Capacitors must be leaded / through-hole**, not SMD. SMD won't fit a breadboard.
3. **Items 10 and 11 are tools/insurance, not parts.** Drop them to save ₹510 if you
   want the minimum — but read why the multimeter earns its place first.

---

## Group 1 — core parts

`project.md` records these as already ordered and in transit. **Skip any you've
already got**; listed here so the order is complete either way.

| Item | Spec | Qty | Link | ₹ |
| --- | --- | --- | --- | --- |
| ESP32 DevKit | ESP32-WROOM-32, 38-pin | 1 | [Robu](https://robu.in/product/esp32-38pin-development-board-wifibluetooth-ultra-low-power-consumption-dual-core/) | 500 |
| MG90S servo | metal gear, **180° — NOT 360°** | 1 | [Robu — TowerPro MG90S 180°](https://robu.in/product/towerpro-mg90s-mini-digital-servo-motor-180-rotation-standard-quality/) | 239 |
| Breadboard | 830 points, solderless | 1 | [Robu](https://robu.in/product/transparent-830-points-solderless-breadboard/) | 110 |
| Jumper wires | M-M **and** M-F, 40-pin sets | 2 | [Robu — Dupont cables](https://robu.in/product-category/dupont-cable/) | 160 |

**Subtotal: ₹1,009**

> ### ⚠️ Buy the 180° MG90S, not the 360° one
> Robu sells both, and the listings look nearly identical. The **360° continuous
> rotation** version cannot hold a position — it spins like a motor and takes speed
> commands, not angles. Every line of firmware in this project assumes a positional
> servo. The 360° version would be silently useless.

---

## Group 2 — power, brownout fix, and Phase 1b

| Item | Spec | Qty | Link | ₹ |
| --- | --- | --- | --- | --- |
| 5 V power adapter | 5 V **3 A**, 5.5×2.1 mm plug | 1 | [Robu — Orange 5V 3A](https://robu.in/product/orange-5v-3a-power-supply-adapter-charger-with-5-5mm-dc-plug/) | 350 |
| DC jack w/ pigtail | female 5.5×2.1 mm, wire leads | 1 | [Robu](https://robu.in/product/dc-jack-connector-female-2-1mm-x-5-5mm-with-wire/) | 40 |
| Bulk capacitor | **1000 µF 16 V, leaded** | 3 | [Robu — Rubycon 1000 µF 16 V](https://robu.in/product/16zlh1000mhfc10x16-rubycon-1000uf-16v-%C2%B120-plugind10xl16mm-aluminum-electrolytic-capacitors-leaded-rohs/) | 45 |
| Ceramic capacitors | assorted kit, incl. 0.1 µF | 1 | [Robu — 30-value kit](https://robu.in/product/ceramic-capacitor-assorted-kit-30-kinds-from-2pf-0-1uf/) | 150 |
| Tactile pushbuttons | 6×6×5 mm, 4-pin | 20-pk | [Robu — pack of 20](https://robu.in/product/6x6x5mm-tactile-push-button-switch-pack-of-20/) | 75 |

**Subtotal: ₹660**

### Why these, specifically

- **3 A, not 2 A.** MG90S stall is **750 mA ±10 % @ 6 V**, so 2 A covers one servo.
  But inrush spikes above steady stall, and the plan scales to several servos on one
  board. 3 A covers ~three with headroom. 5 V (not 6 V) keeps one rail voltage and
  sits safely inside the servo's 4.8–6.0 V range.
- **The DC jack has a wire pigtail, not screw terminals** — bare wires push straight
  into the breadboard rails, one less thing to assemble.
- **Capacitors must be LEADED, not SMD.** Most search hits for both are surface-mount,
  which you cannot use on a breadboard. Both links above are through-hole. Fit the
  1000 µF **across the servo's V+ and GND, close to the servo** — at the far end of a
  long wire it does much less good. **Polarity matters:** the stripe is negative;
  backwards, it can vent.
- **The ceramic kit** covers the 0.1 µF that pairs with the bulk cap (electrolytic
  handles slow bulk sag, ceramic handles high-frequency noise it can't) and gives you
  a drawer of values for everything after.
- **Buttons need no resistor** — the ESP32's internal pull-up handles it (GPIO 4).

> **Do NOT substitute an MB102 breadboard power module.** It's the obvious-looking
> choice and it will fail here — it sources only a few hundred mA and browns out
> exactly when the servo stalls, which is the precise failure you're engineering out.

---

## Group 3 — tools

| Item | Spec | Qty | Link | ₹ |
| --- | --- | --- | --- | --- |
| Digital multimeter | DC volts, DC current, continuity | 1 | [Robu — Haoyue MAS830L](https://robu.in/product/haoyue-mas830l-digital-handheld-multimeter-600-vac-dc/) | 450 |
| Logic level converter | 4-channel bidirectional 3.3 ↔ 5 V | 1 | [Robu — 4-channel](https://robu.in/product/level-converter-4-channel/) | 60 |

**Subtotal: ₹510**

- **The multimeter matters more than it sounds.** The brownout looks *identical* to a
  firmware bug — the board reboots mid-press and you'll be tempted to debug code. A
  meter on the 5 V rail settles it. It's also how you'll measure idle current before
  sizing a battery (see Section D). A [DT830D at ~₹200](https://robu.in/product/digital-multimeter-small-yellow-color-lcd-ac-dc-measuring-voltage-current/)
  works if you want to halve this line.
- **The level converter is insurance, hopefully unused.** The ESP32 drives 3.3 V logic
  while the MG90S expects ~5 V. Most MG90S units read 3.3 V PWM fine — but it's a
  marginal case, and "servo twitches or ignores commands" is what it looks like when
  it isn't. ₹60 against a confusing evening.

---

## Order total

| Group | ₹ |
| --- | --- |
| 1 — core (skip if already ordered) | 1,009 |
| 2 — power + Phase 1b | 660 |
| 3 — tools | 510 |
| Shipping (free above ₹500) | 0 |
| **Everything** | **₹2,179** |
| **If core already ordered** | **₹1,170** |

---

## What Phase 3 (Siri) needs — no extra hardware

HomeSpan makes the ESP32 itself a native HomeKit accessory. No bridge, no hub
purchase, no subscription. **The parts list above is already complete for Siri.**

What it does need, none of it purchasable:

- **A 2.4 GHz WiFi band.** The ESP32 cannot see 5 GHz at all. Routers that broadcast
  one merged SSID with band-steering frequently fail to pair, in a way that reads as
  a firmware bug. Be ready to expose a 2.4 GHz-only SSID temporarily.
- **An iPhone or iPad** with the Home app, to pair the accessory.
- **WiFi credentials in `include/secrets.h`** — gitignored, because this repo is public.

**A HomeKit hub (Apple TV / HomePod) is optional.** "Hey Siri, turn on the fan"
works from your iPhone with no hub while you're on the same WiFi. A hub is only
required for control from *outside* the house, and for automations. Don't buy one
for this project unless you specifically want those.

---

## Later — do NOT order yet

Each depends on a measurement or decision not yet made; buying now means buying twice.

- **3D printing filament** — **PETG, not PLA.** PLA creeps under sustained load and
  softens in a warm room, and this part holds force against a wall for months. Wait
  until the arm is designed (Phase 4).
- **Adhesive tab + tether material** — for the push-pull rocker mechanism (see
  `project.md`). Depends on rocker dimensions.
- **Servos 2..N** — one per extra switch. Order after one switch works end-to-end
  through Siri.
- **[PCA9685 16-channel servo driver](https://robu.in/product/16-channel-12-bit-pwmservo-driver-i2c-interface-pca9685-arduino-raspberry-pi/)**
  (~₹300) — for the multi-gang build. Drives 16 servos over 2 I2C pins with its own
  PWM hardware, and gives a clean place to feed servo power separately from logic.
  **This is what makes the board choice stop mattering** for servo count — see below.
- **A smaller board for the final build** — tempting, but do NOT buy one yet:
  - [ESP32-C3 SuperMini](https://robu.in/product/esp32-c3-development-board-esp32-supermini/)
    is 22.5 × 18 mm and would shrink a single-switch build to roughly SwitchBot size.
  - **But the C3 has only 6 LEDC PWM channels.** Six servos = exactly six, zero
    margin, before ESP32Servo reserves timers. The classic ESP32 has 16. The board
    that shrinks the product is the one that makes scaling harder — unless you use
    the PCA9685 above, which sidesteps it entirely.
  - **If you go Thread/Matter (D3), you need a C6, not a C3** — the C3 has no
    802.15.4 radio. Buying a C3 now silently commits you to WiFi.
  - The SuperMini form factor is widely reported to have **weak WiFi range** from its
    antenna layout, especially in clones. Risky for a device that must stay connected
    behind a switchboard.

  Order of operations: one switch working on the DevKitC → PCA9685 when scaling to
  six → pick a small board last, once WiFi-vs-Thread is decided.
- **Battery parts** — see Section D. Do the power-bank test first.

---

## Can we run it on cells?

Fine for bench testing, viable for the permanent install with WiFi light sleep.

### On the bench (Phase 1/1b) — works

Use **4 × AA NiMH** (Eneloop-type), *not* alkaline.

| | NiMH ×4 | Alkaline ×4 |
| --- | --- | --- |
| Pack voltage | 4.8 V (inside MG90S 4.8–6.0 V range) | 6.0 V nominal, ~6.4 V fresh |
| Internal resistance | ~20–50 mΩ/cell | ~150–300 mΩ/cell, rising as they drain |
| Sag at 750 mA stall | small | **0.5–1 V** |

Alkalines look better on the voltage spec and are the wrong answer — their internal
resistance recreates the exact brownout the separate supply exists to prevent.

Even so, prefer the adapter during bring-up: a pack whose voltage droops as it
discharges is a moving variable, and Phase 1 is exactly when the power supply should
be the one thing that *isn't* a suspect.

### Permanently (Phase 5) — yes, with WiFi light sleep

> **Correction.** An earlier version of this file said battery was impractical and
> quoted ~80 mA idle. That is the ESP32's **untuned default**, not its floor. With
> `esp_wifi_set_ps()` + auto light-sleep, measured idle is **~7.5 mA** at DTIM3 — a
> ~10× difference that changes the conclusion.

**The servo is not the power problem. Idle radio current is.**

| Load | Draw | Per day |
| --- | --- | --- |
| Servo presses (10/day, ~1 s each) | 750 mA peak | **~10 mWh** |
| ESP32 idle, WiFi + auto light-sleep | ~7.5 mA @ 3.3 V | **~600 mWh** |

Light sleep — not deep sleep — is the key. The radio still wakes on every DTIM
beacon, so the accessory stays reachable with sub-second latency. Deep sleep would
break HomeKit; light sleep does not.

**Estimated runtime on one 18650 (3000 mAh ≈ 11 Wh):**

| Configuration | Avg draw | Runtime |
| --- | --- | --- |
| Stock devkit + light sleep | ~20 mA | **~5–7 days** |
| Devkit with power LED + USB-UART disabled | ~8 mA | **~2 weeks** |
| ESP32-C6 + Matter over Thread (sleepy end device) | <1 mA | **months** |

> **The dev board is the hidden cost.** A bare ESP32 module hits ~7.5 mA, but a
> DevKitC also runs a CP2102/CH340 USB-serial chip and a power LED that never sleep —
> typically 10–20 mA on their own, more than the ESP32 itself. **Measure yours with
> the multimeter before sizing a battery.**

For comparison, a commercial SwitchBot Bot gets **600 days on a CR2** — about 55 µA
average. That is only possible over Bluetooth. No WiFi device comes close; it's a
physics problem, not a tuning problem.

---

## D. Portable power — order with Phase 5, not now

### D1. Power bank — simplest, zero new circuitry ⭐ start here

- [ ] Any USB power bank + the ESP32's existing USB cable.
- **The one gotcha:** most power banks **auto-shut-off below ~50–100 mA**, and a
  sleeping ESP32 pulls far less — so the bank switches itself off and your accessory
  dies. You need one advertised as **"low-current mode"** or **"always-on"**. Test
  before committing.

### D2. 18650 + charger + boost — proper portable build

| Item | Spec | Link | ₹ |
| --- | --- | --- | --- |
| Charger module | TP4056 **with protection** (DW01), Type-C | [Robu — TP4056 Type-C](https://robu.in/product/tp4056-1a-li-ion-lithium-battery-charging-module-with-current-protection-type-c/) | 60 |
| Boost converter | MT3608, 3.7 V → 5 V | [Robu — MT3608](https://robu.in/product/mt3608-2a-max-dc-dc-step-up-power-module-booster-power-module/) | 60 |
| 18650 cell | 3000 mAh, **genuine** Samsung/LG | buy from a reputable seller | 350 |

**Subtotal D2: ≈ ₹470**

- **Get the protected TP4056 (with DW01).** Li-ion below ~2.5 V is damaged and can be
  dangerous. The protection IC is ~₹10 of the price. Non-negotiable.
- **TP4056 modules don't load-share.** Running the circuit while charging confuses
  charge termination. Power the device off while charging.
- **MT3608's "2 A" is a headline number.** Boosting 3.7 V → 5 V at 750 mA stall means
  ~1.2 A on the input side, near its comfortable limit. The 1000 µF cap matters
  *more* here, not less.
- **18650 counterfeits are rampant.** Anything claiming 6000 mAh is fake — genuine
  cells top out near 3500 mAh.

### D3. Months, not weeks — Matter over Thread

- **ESP32-C6** or **ESP32-H2** (the classic ESP32 has no 802.15.4 radio).
- Thread allows a **Sleepy End Device** — sub-1 mA, months on a battery — while
  staying reachable to Siri.
- **Requires a Thread border router**: HomePod mini or Apple TV 4K. If you don't own
  one, that dwarfs the battery cost.
- Replaces HomeSpan with the Matter SDK. Substantially harder than Phase 3 as planned.

**Recommendation: D1 now, D2 for a tidy build, D3 only if weekly charging genuinely
fails the use case.**

---

## Measurements

### Received 2026-08-04

Photos of the target board. **6-gang modular switchboard**, single horizontal row,
rocker-style modules. Ample clear wall above and below — mounting space is not a
constraint.

| Measurement | Value | Confidence |
| --- | --- | --- |
| Rocker face width | **20 mm** | AR, 2026-08-11 |
| Rocker face height | **40 mm** | AR, 2026-08-11 — supersedes the bogus 7 cm |
| Gang count | 6 | confirmed from photo |
| Gang pitch | ~23 mm | estimated off the AR photo — **confirm with a ruler** |
| Mounting space | ample above and below | confirmed from photo |

> **The old 7 cm reading is resolved.** It was measuring the whole faceplate, not
> one rocker. Re-measured 2026-08-11 as **20 × 40 mm**, which is what the 1 : 2
> aspect ratio in the photos predicted.
>
> This also reconciles with the standard. Indian modular switches are nominally
> **22 × 45 mm**, but that is the *module including its bezel* — the visible rocker
> face sits inside it. 20 × 40 mm is exactly right for a 22 × 45 mm module, so two
> independent sources now agree.

### What 20 × 40 mm means for the design

- **The rocker pivots at its centre**, so each half is **20 × 20 mm**. The adhesive
  tab goes on the lower half.
- `cad/fingerbot.scad` sizes the tab at **14 × 10 mm** — comfortably inside a
  20 × 20 mm half, with margin for misalignment. **No CAD change needed.**
- At ~23 mm pitch the cradle (28.1 mm wide) still overhangs a single gang, so the
  staggered above/below mounting for the 6-gang build stands.

### Actuation force — NOT a blocker

The design space is one variable (arm length) over a narrow range (20–30 mm), so this
can be settled empirically.

**Print three arms and test:**

- [ ] Print arms at **20 mm, 25 mm, 30 mm**.
- [ ] Try **20 mm first** — shortest arm, maximum force (~9.8 N @ 6 V, above
      SwitchBot's 8 N).
- [ ] Go longer only if you need more travel at the rocker.

If even the 20 mm arm won't flip it, the servo is undersized and no geometry fixes
that — the answer is a stronger servo (MG996R). That outcome is itself the measurement.

Indian modular rockers are typically light (~2–4 N), so a 20 mm MG90S arm should have
healthy margin.

**How to measure it, if you want a real number anyway.**

*Method A — hanging weight. No equipment to buy, and it measures PULL force, which is
what the tether design needs.*

1. Stick a tab of strong tape (folded to leave a loop) on the rocker's lower half.
2. Tie a string to it and hang an empty sealed bottle.
3. Add water gradually — take the bottle down to fill, cap it, rehang.
4. When the rocker flips, measure the water in a jug. **1 ml = 1 g.** Add the
   bottle's own weight.

> ⚠️ Fill away from the board and keep the bottle capped. That's mains wiring behind
> the plate.

*Method B — kitchen scale + video.* Hold it sideways in the pressing position, tare to
zero, start a video of the display, press it into the rocker until it clicks, then
scrub back to the click frame. The video works around scales not holding a peak.

*Method C — luggage/fish scale (~₹200).* Hook onto the taped tab and pull.

**Converting:** newtons = grams ÷ 102.

| Reading | Force | Verdict |
| --- | --- | --- |
| < 400 g | < 3.9 N | easy — any arm 20–30 mm works |
| 400–800 g | 3.9–7.8 N | use a 20–25 mm arm |
| > 800 g | > 7.8 N | MG90S marginal — consider MG996R |

### Still useful

- [x] ~~Rocker **height × width**~~ — **20 × 40 mm**, measured 2026-08-11.
- [ ] **Gang pitch** — centre-to-centre between adjacent modules. Estimated ~23 mm
      off the AR photo; worth 30 seconds with a ruler to confirm, because it decides
      how badly the 6-gang build has to stagger.
- [ ] Rocker **throw** — how far the end travels off→on, mm. **Now the main gap.**
      Decides the servo sweep angle. Press one side and eyeball the step against a
      ruler edge; anything from 2–4 mm is typical.
- [ ] How far the plate **protrudes from the wall**, mm. Sets how far the mount
      must stand off.
- [ ] **Side-on photo** of one switch, rocker held in each position. Would give the
      throw and the protrusion together, from one photo.

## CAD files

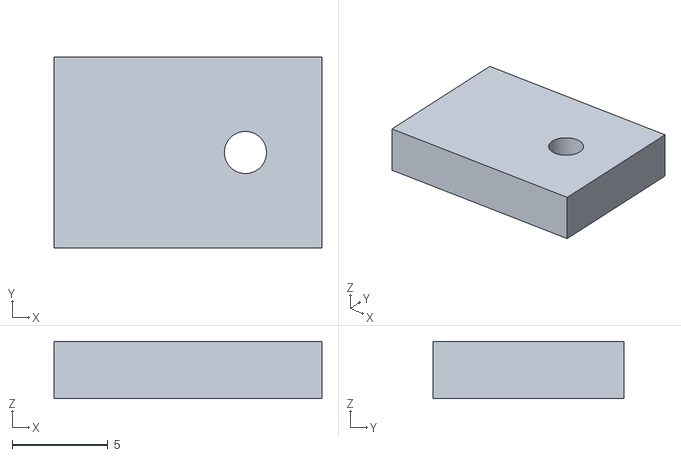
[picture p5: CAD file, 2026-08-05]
cad/stl/tab.stl
14.0 x 10.0 x 3.00

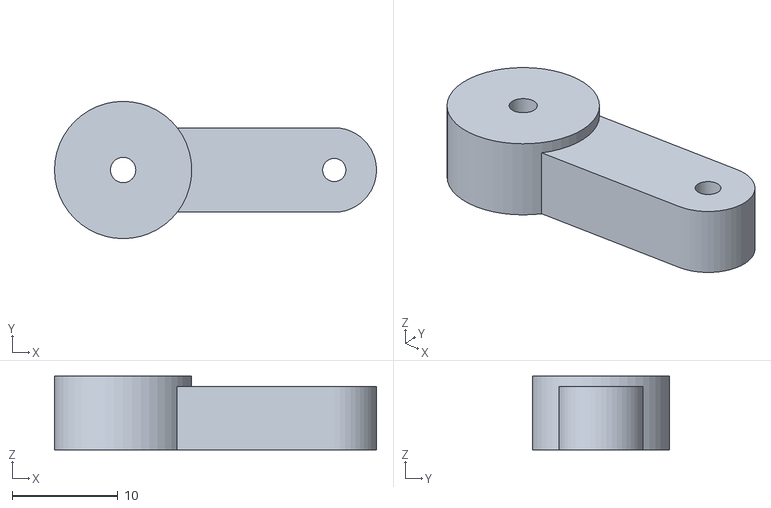
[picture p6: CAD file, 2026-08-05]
cad/stl/arm20.stl
30.5 x 13.0 x 7.00

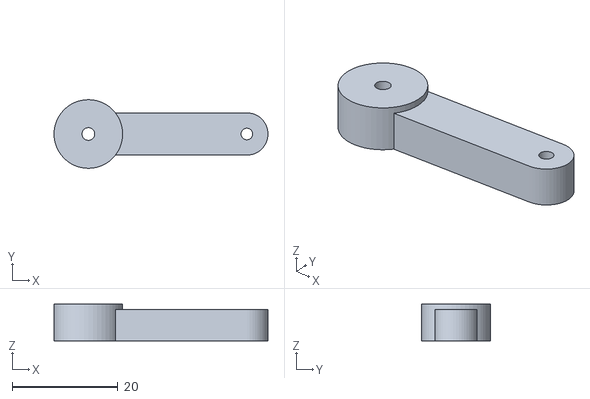
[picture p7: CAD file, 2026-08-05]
cad/stl/arm30.stl
40.5 x 13.0 x 7.00

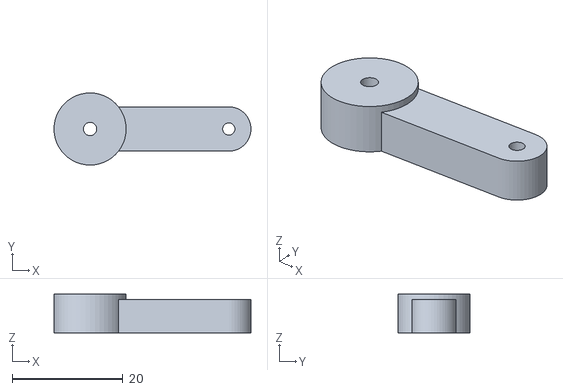
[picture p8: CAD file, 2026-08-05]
cad/stl/arm25.stl
35.5 x 13.0 x 7.00

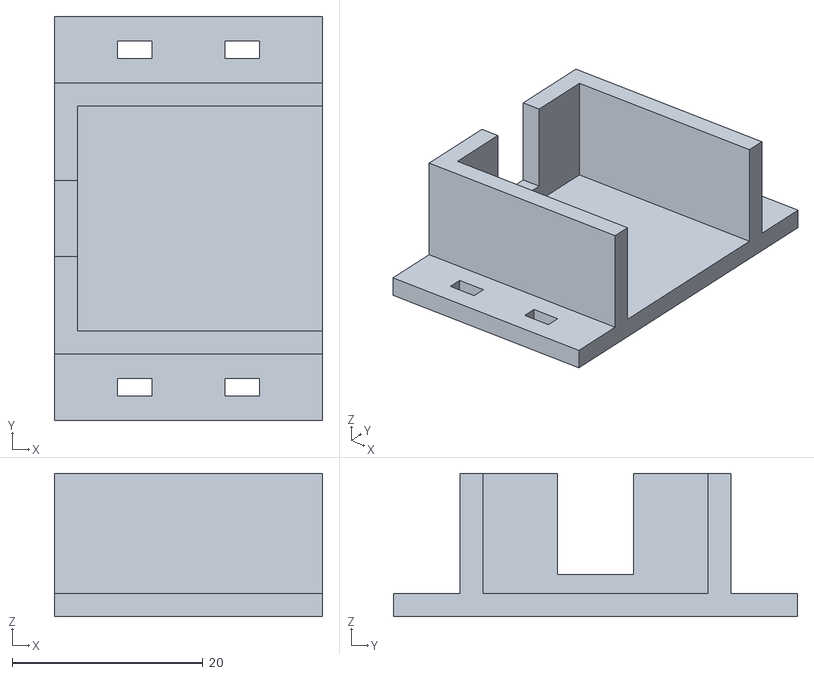
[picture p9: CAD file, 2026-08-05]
cad/stl/cradle.stl
28.1 x 42.4 x 15.0

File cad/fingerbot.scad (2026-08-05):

/*
  DIY Fingerbot — mechanical parts (Phase 4)

  Three printed parts:
    cradle  — holds the MG90S, flat back for VHB tape onto the wall
    arm     — lever that pushes/pulls the rocker. Print 20, 25 and 30 mm.
    tab     — small adhesive pad for the rocker, with a tether hole

  ---------------------------------------------------------------------------
  THESE DIMENSIONS COME FROM DATASHEETS, NOT FROM MEASURING THE REAL PARTS.
  Print ONE cradle and ONE arm first, test-fit them against the actual servo,
  then adjust the numbers below before printing anything else. Everything is
  parametric precisely so that's a one-line change, not a redesign.
  ---------------------------------------------------------------------------

  Render one part at a time:
      openscad -D 'part="cradle"' -o cradle.stl fingerbot.scad
      openscad -D 'part="arm"' -D 'arm_len=20' -o arm20.stl fingerbot.scad
      openscad -D 'part="tab"' -o tab.stl fingerbot.scad

  Print in PETG, not PLA. This part holds force against a wall for months and
  PLA creeps under sustained load and softens in a warm room.

  ORIENTATION, once mounted: the servo lies on its side below the switch, with
  its output shaft axis horizontal and parallel to the wall, so the arm sweeps
  in a vertical plane perpendicular to the wall — pushing the rocker in, and
  pulling it back out via a tether to the tab. See project.md, "The rocker
  problem".
*/

part = "all";  // [all, cradle, arm, tab]

/* [MG90S servo — verify against your actual part] */
// body, excluding mounting flange
servo_l     = 22.8;   // long axis of the body; runs VERTICALLY on the wall
servo_w     = 12.2;   // thin axis; this becomes depth OUT from the wall
servo_h     = 22.5;   // along the output shaft axis; runs horizontally

/* [Arm] */
arm_len       = 20;    // hub centre to tip. Print 20 / 25 / 30 and test.
arm_w         = 8;     // beam width
arm_t         = 6;     // beam thickness
hub_d         = 13;    // outer diameter of the arm's hub
hub_h         = 7;     // hub height — must exceed horn_hub_h

// The arm grips the servo's STOCK plastic horn rather than the spline itself.
// A 20-tooth spline at ~4.8 mm is below reliable FDM resolution, and a printed
// one would strip. These are the horn's dimensions, so measure them first.
horn_hub_d    = 7.4;   // round boss at the centre of the stock horn
horn_hub_h    = 4.2;
horn_blade_w  = 5.4;   // width of the single-arm blade
horn_blade_t  = 1.9;   // blade thickness

// How far along the beam the blade slot runs. This only needs to be long enough
// to stop the arm rotating on the horn — the centre screw does the retaining.
// Keep it WELL SHORT of arm_len: the slot removes horn_blade_t from the bottom
// of the beam, and whatever is left above it is the entire load path. At
// arm_t = 6 and a 1.9 mm slot that leaves 4.1 mm, which is fine. Running the
// slot the full length of a thin beam would leave a weak channel instead.
horn_capture_l = 12;
shaft_screw_d = 2.4;   // the servo's own centre retaining screw

tip_hole_d    = 2.2;   // tether hole at the arm tip

/* [Cradle] */
wall  = 2.4;   // shell thickness
clear = 0.4;   // print clearance around the servo body
lip   = 7;     // base flange either side, carries the zip-tie slots
zip_w = 3.6;   // zip tie width
zip_t = 1.8;   // zip tie thickness

/* [Rocker tab] */
tab_l = 14;
tab_w = 10;
tab_t = 3;

/* [Hidden] */
$fn = 48;
eps  = 0.01;

// ---------------------------------------------------------------------------

// Tray the servo drops into. Flat underside (z=0) is the adhesive face.
// Held by two zip ties rather than screws: the flange screw positions are the
// least certain dimension here, and zip ties don't care if we're 1 mm out.
module servo_cradle() {
    pocket_x = servo_h + 2 * clear;
    pocket_y = servo_l + 2 * clear;
    body_x   = pocket_x + 2 * wall;
    body_y   = pocket_y + 2 * wall;
    total_z  = wall + servo_w + clear;

    difference() {
        union() {
            // base plate, extended sideways to carry the zip slots
            translate([0, -lip, 0])
                cube([body_x, body_y + 2 * lip, wall]);
            // walls
            cube([body_x, body_y, total_z]);
        }

        // servo pocket, open at the top
        translate([wall, wall, wall])
            cube([pocket_x, pocket_y, servo_w + clear + 1]);

        // shaft side left fully open so the horn and arm clear the shell
        translate([body_x - wall - eps, wall, wall])
            cube([wall + 1, pocket_y, servo_w + clear + 1]);

        // cable exit at the opposite end
        translate([-1, body_y / 2 - 4, wall + 2])
            cube([wall + 2, 8, servo_w]);

        // zip-tie slots through the base flange
        for (x = [body_x * 0.3, body_x * 0.7])
            for (y = [-lip / 2, body_y + lip / 2])
                translate([x - zip_w / 2, y - zip_t / 2, -1])
                    cube([zip_w, zip_t, wall + 2]);
    }
}

// The lever. Hub captures the stock horn; tip has a hole for the tether.
module fingerbot_arm(len = arm_len) {
    difference() {
        union() {
            cylinder(d = hub_d, h = hub_h);
            translate([0, -arm_w / 2, 0])
                cube([len, arm_w, arm_t]);
            translate([len, 0, 0])
                cylinder(d = arm_w, h = arm_t);
        }

        // recess for the stock horn's central boss
        translate([0, 0, -eps])
            cylinder(d = horn_hub_d, h = horn_hub_h);

        // slot for the horn's blade, radially along +X. Deliberately shorter
        // than the beam so the top of the beam stays solid — see horn_capture_l.
        translate([0, -horn_blade_w / 2, -eps])
            cube([min(horn_capture_l, len), horn_blade_w, horn_blade_t]);

        // servo's own centre screw passes right through
        translate([0, 0, -1])
            cylinder(d = shaft_screw_d, h = hub_h + 2);

        // tether hole at the tip
        translate([len, 0, -1])
            cylinder(d = tip_hole_d, h = arm_t + 2);
    }
}

// Sticks to the rocker face. The tether ties through the hole, letting the arm
// PULL as well as push — which is what makes one contact point switch both ways.
module rocker_tab() {
    difference() {
        cube([tab_l, tab_w, tab_t]);
        translate([tab_l - 4, tab_w / 2, -1])
            cylinder(d = tip_hole_d, h = tab_t + 2);
    }
}

// ---------------------------------------------------------------------------

if (part == "all") {
    servo_cradle();
    translate([0, 55, 0])  fingerbot_arm(20);
    translate([0, 70, 0])  fingerbot_arm(25);
    translate([0, 85, 0])  fingerbot_arm(30);
    translate([0, 100, 0]) rocker_tab();
} else if (part == "cradle") {
    servo_cradle();
} else if (part == "arm") {
    fingerbot_arm(arm_len);
} else if (part == "tab") {
    rocker_tab();
}

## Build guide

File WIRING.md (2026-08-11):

# Wiring & First Power-On

Read this **before** connecting anything. The riskiest moment in this project is the
first power-up: there's a polarised capacitor, a separate supply, and possibly a
cut-and-stripped adapter lead. Reversed polarity kills the ESP32 instantly and can
make the capacitor vent.

Working through this as a checklist turns day one into a procedure instead of an
improvisation.

---

## The key idea: two power sources, one ground

During bench testing the ESP32 and the servo are powered **separately**:

| What | Powered by | Why |
| --- | --- | --- |
| ESP32 | **USB from your PC** | also carries flashing + serial monitor |
| Servo | **5 V adapter** | stall spikes must never touch the ESP32's rail |
| Both | **shared GND** | required, or the servo can't read the signal |

> ### ⚠️ Do NOT connect the adapter's + to the ESP32's VIN or 5V pin
> With USB also plugged in, that back-feeds one supply into the other. The only wire
> between the two power domains is **ground**.

The shared ground is not optional. The servo's PWM signal is measured relative to
ground; without a common reference the servo sees garbage and either sits still or
twitches — a failure that looks exactly like a code bug.

---

## Layout

```
   5V ADAPTER                          BREADBOARD
   ┌────────┐
   │  5V 2A │  red  (+) ─────────────▶ ( + ) RED RAIL ──────┬─────────┐
   │        │                                               │         │
   │        │  black(−) ─────────────▶ ( − ) BLUE RAIL ─┬───┼────┬────┼──┐
   └────────┘                                           │   │    │    │  │
                                                        │   │    │    │  │
                                    1000 µF ── stripe ──┘   │    │    │  │
                                       ▲                    │    │    │  │
                                       └── + leg ───────────┘    │    │  │
                                                                 │    │  │
                                    0.1 µF ────────────────────  ┘    │  │
                                    (parallel, no polarity)           │  │
                                                                      │  │
   MG90S SERVO                                                        │  │
     red    (V+)  ──────────────────────────────────────────────────  ┘  │
     brown  (GND) ─────────────────────────────────────────────────────  ┘
     orange (PWM) ─────────────────────────▶ ESP32 GPIO 18

   ESP32 DevKitC-32E
     GND  ──────────────────────────────────▶ ( − ) BLUE RAIL   ◀── CRITICAL
     USB  ──────────────────────────────────▶ your PC

   BUTTON (Phase 1b only)
     leg 1 ─────────────────────────────────▶ ESP32 GPIO 4
     leg 2 ─────────────────────────────────▶ ESP32 GND
```

### Connection table

| From | To | Notes |
| --- | --- | --- |
| Adapter + | Breadboard **red** rail | confirm polarity first — see checklist |
| Adapter − | Breadboard **blue** rail | |
| 1000 µF **+** leg | Red rail | **near the servo**, not the far end |
| 1000 µF **stripe** leg | Blue rail | stripe = negative. Backwards it can vent |
| 0.1 µF (either leg) | Red rail | no polarity |
| 0.1 µF (other leg) | Blue rail | |
| Servo red | Red rail | |
| Servo brown/black | Blue rail | |
| Servo orange/yellow | ESP32 **GPIO 18** | signal only |
| **ESP32 GND** | **Blue rail** | **the common ground — do not skip** |
| Button leg 1 | ESP32 **GPIO 4** | Phase 1b |
| Button leg 2 | ESP32 GND | no resistor needed; internal pull-up |

**Capacitor placement matters.** Put the 1000 µF physically close to the servo's
power connection. Its job is to supply the stall current surge locally; at the far
end of a long breadboard run, the wire resistance between it and the servo undoes
most of the benefit.

---

## Pre-flight checklist

Work top to bottom. Don't skip step 2 — it's the one that saves the ESP32.

### Before any connections

- [ ] **1.** Unplug everything. Adapter out of the wall, USB out of the ESP32.
- [ ] **2. Identify adapter polarity with the multimeter.** ⭐
      Plug the adapter into the wall with its output leads free and touching nothing.
      Set the meter to **DC volts (20 V range)**. Red probe on one lead, black on the
      other.
      - Reads **+5 V** → red probe is on **positive**.
      - Reads **−5 V** → red probe is on **negative**; swap your understanding.
      - Reads ~0 V or wildly off → bad adapter, stop.
- [ ] **3. Mark the positive lead** with tape or a marker. Do it now, while you know.
- [ ] **4.** Unplug the adapter from the wall again.

### Build the circuit (unpowered)

- [ ] **5.** Adapter **+** → red rail. Adapter **−** → blue rail.
- [ ] **6.** 1000 µF across the rails near where the servo will sit.
      **Stripe leg to the blue (negative) rail.** Double-check this one.
- [ ] **7.** 0.1 µF across the same rails, either way round.
- [ ] **8.** Servo red → red rail, brown → blue rail.
- [ ] **9.** Servo orange → ESP32 GPIO 18.
- [ ] **10. ESP32 GND → blue rail.** The single most-forgotten wire.
- [ ] **11.** Confirm the adapter's **+ is not** connected to ESP32 VIN, 5V, or 3V3.

### Verify before powering (still unpowered)

- [ ] **12.** Meter on **continuity**. Probe ESP32 GND and the blue rail — should beep.
- [ ] **13.** Probe red rail and blue rail — should **NOT** beep. A beep means a short;
      find it before applying power.
- [ ] **14.** Probe red rail against ESP32 3V3 and 5V pins — should **NOT** beep.

### Power up, in this order

- [ ] **15.** Plug in the **adapter only**. ESP32 still unplugged.
- [ ] **16.** Meter on DC volts across the rails. Expect **4.8 – 5.2 V**, correct
      polarity. Wrong or missing → stop and recheck.
- [ ] **17.** Now plug the **USB** into the ESP32.
- [ ] **18.** Flash the baseline:
      ```
      pio run -e phase1_autopress -t upload
      pio device monitor
      ```
- [ ] **19.** Expect `Fingerbot Phase 1 ready. Auto-pressing every 3s...` and the arm
      sweeping every 3 seconds.

---

## If it doesn't work

| Symptom | Likely cause | Check |
| --- | --- | --- |
| **No COM port exists at all**, `pio device list` empty | **missing CP2102N driver** | see below — this is *not* the same as "nothing on serial" |
| Nothing on serial | wrong baud / wrong port | monitor is 115200; check the COM port |
| Serial fine, servo still | missing common ground | step 10 — the most common miss |
| Serial fine, servo still | 3.3 V signal too weak | fit the level converter |
| **ESP32 reboots exactly when the arm pushes hardest** | **brownout** | see below |
| Servo twitches constantly | noisy/insufficient supply | check the 1000 µF is fitted and close to the servo |
| Servo spins continuously, never holds | **you have the 360° servo** | wrong part — must be the 180° version |

### No COM port at all — the CP2102N driver

**This is different from "nothing on serial", and much more confusing.** There is no
port to select, no wrong baud rate to fix. `pio device list` prints nothing, the
upload fails with `Please specify upload_port`, and it looks like a dead board or a
charge-only cable. It is neither.

The DevKitC-32E talks to the PC through a **CP2102N** USB-UART bridge
(`VID_10C4 & PID_EA60`). Windows 11 ships no driver for it, and **Windows Update
will not find one** — "Search automatically for drivers" reports failure. Device
Manager shows the device under *Other devices* with `CM_PROB_FAILED_INSTALL`
(Code 28).

Diagnose it in one command — if this returns anything, the board is alive and only
the driver is missing:

```powershell
Get-PnpDevice -PresentOnly | Where-Object { $_.FriendlyName -match 'CP210' }
```

Fix: download the **Silicon Labs CP210x Universal Windows Driver**, then from an
**elevated** shell:

```powershell
pnputil /add-driver <path>\silabser.inf /install
```

The device then moves to *Ports (COM & LPT)* as `Silicon Labs CP210x USB to UART
Bridge (COMn)`. Done on this machine 2026-08-11; only needed again on a rebuild.

### The brownout, specifically

Reboot at the moment of maximum push is *the* signature failure of this project. It
looks exactly like a firmware bug and no amount of code reading will fix it.

Diagnose it: meter on DC volts across the rails **while the servo presses**. If the
reading dips well below 5 V at the moment of stall, that's it.

Fixes in order: confirm the 1000 µF is actually fitted and near the servo → confirm
the servo is on the adapter and not the ESP32's 5V pin → move to a higher-current
adapter.

Cheap meters update only 2–3 times a second and may miss a brief dip. The reboot
itself is the more reliable symptom.

---

## Phase 1b addition

Once Phase 1 works, add the button — **one new thing**:

- [ ] Button leg 1 → GPIO 4, leg 2 → ESP32 GND (the `−` rail *is* ESP32 ground).
- [ ] `pio run -e phase1b_button -t upload`
- [ ] Expect `Fingerbot Phase 1b ready.` and no motion until you press.

If the servo stops working at this point, flash `phase1_autopress` again. If that
still works, the fault is in the button wiring, not the servo — which is exactly why
the baseline is kept around.

### Test GPIO 4 without a button first

Skip the switch entirely for the first test. Put the **female** end of an M-F jumper
on pin `4`, and **tap the male end into a `−` rail hole**. That tap *is* a press —
pin 4 idles HIGH on its internal pull-up, and grounding it is all a button does.
Perfectly safe: a few microamps through a ~45 kΩ resistor.

This separates "does the firmware work" from "is my switch seated right", which are
two completely different problems. Tapping a bare wire also bounces far worse than
any switch, so it's a harder test of the debouncer than the button will ever be —
8 taps produced exactly 8 presses on 2026-08-11.

> ⚠️ **`−` rail only.** The `+` rail would put 5 V into GPIO 4, and ESP32 pins are
> 3.3 V logic and **not** 5 V tolerant.

### A 4-pin tactile switch has only TWO circuits

This wastes an evening if you don't know it. The four legs are two **permanently
joined pairs** — the two legs on the same side of the body are the *same wire*,
pressed or not. Pressing bridges one pair to the other.

```
   leg 1 ═══╗                      ╔═══ leg 3
            ║  ▓▓ METAL A ▓▓       ║  ▓▓ METAL B ▓▓
   leg 2 ═══╝                      ╚═══ leg 4
            └──────── gap ─────────┘      pressing closes the gap
```

Wire across a joined pair and the pin is grounded permanently. The firmware then
fires **once** at boot — `Debouncer::update()` returns true only on the edge into
pressed — and never again, because the release never comes.

**Mount it across the centre channel, then wire it DIAGONALLY.** Take your two
wires from legs that are diagonally opposite — one from the upper bank, one from
the lower bank, offset by a row:

```
        a b c d e │ f g h i j
   30   ● ● ● ● ● │ ● ●[■]● ●   ← wire to the − rail
   31   ● ● ● ●[L]│[L]● ● ● ●   ← switch legs straddle the channel
   32   ● ● ● ●[L]│[L]● ● ● ●
   33   ● ●[■]● ● │ ● ● ● ● ●   ← wire to GPIO 4
```

Diagonally opposite legs sit on opposite sides of the body, so they are **always**
one from each joined pair — correct no matter which way the switch went in.

Straight across the same row only works if the switch happens to be oriented the
right way, and **both orientations look identical from outside**. Going diagonal
sidesteps the question entirely. Learned the hard way 2026-08-11: straight-across
gave a permanent closed circuit; the same switch, untouched, worked immediately
when rewired diagonally.

To check before powering, meter on continuity across your two chosen holes:
released → **silent**, pressed → **beep**. A constant beep means you still picked a
joined pair — move one wire to the switch's other row.

Or skip the meter and **let the servo be your tester**: wire it up and press.
Swings on each press = correct. Fires once at boot then never again = joined pair.

---

## Phase 1c addition

**No wiring change at all** — identical circuit to 1b. Purely firmware.

- [ ] `pio run -e phase1c_toggle -t upload`
- [ ] Expect `Fingerbot Phase 1c ready. Press the button to toggle.`
- [ ] Each press alternates: `>> Turning ON` / `>> Turning OFF`, with the arm
      swinging to a *different* angle each way and returning to neutral between.

This is where you calibrate the three angles against the real switch. In
`src/phase1c_toggle.cpp`:

| Constant | Default | What to tune it for |
| --- | --- | --- |
| `REST_ANGLE` | 90 | arm clear of the rocker, touching nothing |
| `ON_ANGLE` | 60 | far enough to flip it one way |
| `OFF_ANGLE` | 120 | far enough to flip it the other way |

**If it turns on when you expected off, swap `ON_ANGLE` and `OFF_ANGLE`.** That's
the entire fix — the logic doesn't care which direction is which.

---

## Finding those angles the fast way

Don't hand-edit and reflash for every guess. Flash the calibration console once
and work in the serial monitor:

```
pio run -e phase1d_calibrate -t upload
pio device monitor
```

Same wiring again (the button is simply unused). Then:

| Command | Does |
| --- | --- |
| `go <0-180>` | move there, don't store it — use this to hunt |
| `on` / `off` / `rest <0-180>` | store that angle and move there |
| `hold <0-5000>` | how long to stay at an angle, ms |
| `test` | full rest → on → rest → off → rest cycle |
| `show` | print current values |
| `save` | persist to flash |

Typical session:

```
> go 70
> go 62          <- rocker clicks
> on 62
> go 118
> off 118
> test
> save
```

Values are stored in flash, so a **brownout reset won't lose your work** — which
matters here, because stalling against a stiff switch is exactly what triggers one.

When `show` gives you numbers you're happy with, paste them into
`src/phase1c_toggle.cpp` as the new defaults.

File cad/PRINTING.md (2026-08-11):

# Print Instructions — DIY Fingerbot parts

Hand this to whoever is printing, along with the five `.stl` files in `cad/stl/`.

Everything here is small. **Total is roughly 25 g of filament and about 2 hours**
of printer time for the whole set.

---

## What to print

| File | Qty | What it is |
| --- | --- | --- |
| `cradle.stl` | 1 | Tray that holds the servo. Flat back goes against the wall |
| `arm20.stl` | 1 | Lever, 20 mm |
| `arm25.stl` | 1 | Lever, 25 mm |
| `arm30.stl` | 1 | Lever, 30 mm |
| `tab.stl` | 2 | Small pad that sticks to the light switch |

**Please print all three arm lengths.** They are not alternatives to choose
between on screen — the right length is decided by testing against a real switch,
and the three exist so that test can happen without another print run. They are
about 3 g each.

Two `tab.stl` because they are tiny and one usually gets destroyed removing the
adhesive.

---

## Material: PETG

**Not PLA.** These parts live on a wall for months in a warm room, and PLA loses
stiffness well below its glass transition.

If only PLA is available, print anyway — the parts are still useful for checking
that the dimensions are right. Just say which material was used, because PETG runs
0.1–0.3 mm larger than PLA on small features, which matters here.

---

## Settings

| Setting | Value | Why |
| --- | --- | --- |
| Layer height | 0.2 mm | nothing here needs finer |
| Perimeters / walls | **4** | the arm is structural; walls carry the load, not infill |
| Infill | 40 % | anything above this is wasted on parts this small |
| Supports | **None needed** | see below |
| Scale | **100 %** | do not scale. Dimensions are in mm and must be exact |
| Brim | optional | only if PETG lifts on your bed |

### Orientation — print as the STL comes

All five files are already oriented correctly. Do not rotate them.

- **Arms:** flat, hub and beam on the bed. This is deliberate — the bending load
  then runs *within* the layers rather than across them, so layer adhesion is not
  in the load path. Rotating these upright would make them snap.
- **Cradle:** base plate on the bed, tray opening upward.
- **Tabs:** flat.

### Why no supports

The arms have two cavities in the underside — a 7.4 mm round recess and a 5.4 mm
slot — that the printer bridges over. Both spans are short and bridge cleanly.
Supports inside them would be worse than useless, because leftover support debris
in those cavities stops the arm seating on the servo horn.

The cradle's cable slot is open at the top, so there is nothing to bridge.

---

## What matters most

**The arm's hub is the critical part.** It has a round recess and a narrow slot
that grip the servo's stock plastic horn. Those dimensions came from a datasheet
rather than a measured part, so this print is partly a test of whether they are
right.

If those cavities come out filled in, stringy, or badly under-size, the arm cannot
mount at all. A clean underside on the arms matters more than the finish anywhere
else.

No need to fix anything if it comes out wrong — just say what looked off. The
source is parametric, so corrections are one-line changes and a re-export.

---

## Source

Generated from `cad/fingerbot.scad` (OpenSCAD). Regenerate the STLs with
`cad\render.ps1` after any change to the parameters.

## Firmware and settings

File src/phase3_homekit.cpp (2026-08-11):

/*
  DIY Fingerbot — Phase 3 firmware (Siri / Apple Home via HomeSpan)
  ------------------------------------------------------------------
  "Hey Siri, turn on the fan" swings the arm. The pushbutton still works too.

  HomeSpan makes the ESP32 itself a **native HomeKit accessory** — no bridge, no
  hub purchase, no subscription, no cloud account. Apple Home talks straight to
  this board over your LAN.

    pio run -e phase3_homekit -t upload
    pio device monitor

  TWO WAYS TO TRIGGER IT, and they stay in agreement:

    Siri / Home app  ->  update()          -> actuate -> HomeKit already knows
    Pushbutton       ->  loop()            -> actuate -> setVal() TELLS HomeKit

  That `setVal()` is the whole point of having the button here. Without it, you'd
  press the button, the light would change, and Apple Home would still show the
  old state — so the next Siri command would be a no-op and look broken.

  ---------------------------------------------------------------------------
  WIRING IS IDENTICAL TO PHASE 1b/1c. Nothing to re-plug. See WIRING.md.

    servo signal (orange/yellow) -> GPIO 18
    servo V+     (red)           -> +5V of a SEPARATE 5V supply  (NOT the ESP32)
    servo GND    (brown/black)   -> GND of that supply
    ESP32 GND    ---------------- -> GND of that supply   (COMMON GROUND — required)
    button leg 1                 -> GPIO 4     (wire it DIAGONALLY, see WIRING.md)
    button leg 2                 -> ESP32 GND / the `−` rail
  ---------------------------------------------------------------------------

  BEFORE FLASHING: copy include/secrets.h.example to include/secrets.h and put
  your WiFi details in it. That file is gitignored — this repo is public.

  2.4 GHz ONLY. The ESP32 cannot see 5 GHz. A router broadcasting one merged SSID
  with band-steering often fails to associate, and it reads as a firmware bug.

  FIRST BOOT: watch the serial monitor. HomeSpan prints its progress connecting to
  WiFi, then the pairing details. In Apple Home: Add Accessory -> More options...
  -> the Fingerbot appears -> enter the code.

  STILL UNSOLVED: if somebody flips the switch BY HAND, nothing here can know. The
  button path below is not a fix for that — it only covers changes this device
  makes itself. See the KNOWN LIMITATION note in switch_state.h.
*/

#include <Arduino.h>
#include <ESP32Servo.h>
#include "HomeSpan.h"
#include "debounce.h"
#include "switch_state.h"
#include "secrets.h"

Servo fingerArm;
const int SERVO_PIN  = 18;
const int BUTTON_PIN = 4;      // avoid strapping pins (0, 2, 12, 15) for inputs

// ---- Adjustable settings ----
// Same three angles as Phase 1c, and still PLACEHOLDERS. Phase 1d's calibration
// console finds the real ones against the actual switch. REST is neutral, touching
// nothing, so the arm never holds the rocker down.
//
// If Siri turns things the wrong way round, swap ON_ANGLE and OFF_ANGLE. That is
// the whole fix — the logic doesn't care which direction is which.
//
// KEEP THESE IN STEP WITH phase1c_toggle.cpp.
const int REST_ANGLE = 90;
const int ON_ANGLE   = 60;
const int OFF_ANGLE  = 120;

const int HOLD_MS = 500;               // how long to stay at the press angle
const unsigned long DEBOUNCE_MS = 50;  // proven at 14 presses for 14 pushes

Debouncer   button(DEBOUNCE_MS);
SwitchState wallSwitch;   // assumes OFF at boot — matches Characteristic::On(0)

// Move the arm to `angle`, hold, then return to neutral.
void actuate(int angle) {
  fingerArm.write(angle);
  delay(HOLD_MS);
  fingerArm.write(REST_ANGLE);
  delay(200);              // let it settle
}

// Carry out whatever the state machine decided, whoever asked for it.
void applyAction(const char *source, Action action) {
  switch (action) {
    case Action::TurnOn:
      Serial.printf(">> %s: turning ON\n", source);
      actuate(ON_ANGLE);
      break;

    case Action::TurnOff:
      Serial.printf(">> %s: turning OFF\n", source);
      actuate(OFF_ANGLE);
      break;

    case Action::None:
      Serial.printf(">> %s: already in that state, not moving\n", source);
      break;
  }

  Serial.printf("   switch is now %s\n\n", wallSwitch.isOn() ? "ON" : "OFF");
}

// The HomeKit accessory itself. Appears in Apple Home as a switch you can tap,
// ask Siri about, and put in scenes and automations.
struct DEV_Fingerbot : Service::Switch {
  SpanCharacteristic *power;

  DEV_Fingerbot() : Service::Switch() {
    // Initial value 0 = off, so HomeKit's idea of the state matches
    // SwitchState's cold-boot assumption. Keep these two in step.
    power = new Characteristic::On(0);
  }

  // Called whenever Home asks for a change — a tap, Siri, a scene, an automation.
  boolean update() {
    // THIS is why switch_state.h is a class and not a bool. Home re-sends state
    // freely: opening the app, a scene firing, or two commands in quick
    // succession can all deliver "turn on" when it is already on. Actuating on a
    // redundant request would press an already-on rocker and turn the light OFF.
    // requestOn() returns Action::None in that case and we don't move.
    //
    // Observed in the wild 2026-08-11, within 100 s of first pairing.
    applyAction("HomeKit", wallSwitch.requestOn(power->getNewVal()));

    // NOTE: actuate() blocks for ~700 ms, so homeSpan.poll() pauses for that long.
    // Comfortably inside HomeKit's response window and fine for one accessory.
    // Revisit if this ever drives several servos.
    return true;
  }

  // Called from loop() on a debounced physical button press.
  void toggleFromButton() {
    applyAction("Button", wallSwitch.toggle());

    // Push the new state up to HomeKit so Apple Home reflects reality. Skip this
    // and Home goes stale: it would still believe the old state, so the next Siri
    // command would resolve to Action::None and do nothing, which looks broken.
    power->setVal(wallSwitch.isOn());
  }
};

DEV_Fingerbot *fingerbot = nullptr;

void setup() {
  Serial.begin(115200);

  pinMode(BUTTON_PIN, INPUT_PULLUP);

  // IMPORTANT: ESP32Servo needs its PWM timers allocated BEFORE attach(),
  // or the servo silently never moves. Do not remove these four lines.
  ESP32PWM::allocateTimer(0);
  ESP32PWM::allocateTimer(1);
  ESP32PWM::allocateTimer(2);
  ESP32PWM::allocateTimer(3);

  fingerArm.setPeriodHertz(50);            // standard 50 Hz servo
  fingerArm.attach(SERVO_PIN, 500, 2400);  // min/max pulse width (µs)
  fingerArm.write(REST_ANGLE);

  // Credentials and pairing code must be set BEFORE begin().
  //
  // Only push the hardcoded SSID if secrets.h has actually been filled in.
  // Left as placeholders, we say nothing and let HomeSpan's own setup take over:
  // type `W` in the serial monitor and it SCANS and lists the networks it can
  // see, then prompts for the password and stores it in flash.
  //
  // That scan is also the definitive 2.4 GHz test — the ESP32 has no 5 GHz radio,
  // so anything appearing in that list is by definition a network it can use.
  //
  // Both must be filled in — a real SSID with a placeholder password would fail
  // to associate AND overwrite anything `W` had stored, which is a nasty loop.
  if (strcmp(WIFI_SSID, "PUT-YOUR-2.4GHZ-SSID-HERE") != 0 &&
      strcmp(WIFI_PASSWORD, "PUT-YOUR-WIFI-PASSWORD-HERE") != 0) {
    homeSpan.setWifiCredentials(WIFI_SSID, WIFI_PASSWORD);
  }

  homeSpan.setPairingCode(HOMEKIT_PAIRING_CODE);

  homeSpan.begin(Category::Switches, "Fingerbot");

  new SpanAccessory();
    new Service::AccessoryInformation();
      new Characteristic::Identify();
      new Characteristic::Manufacturer("DIY");
      new Characteristic::Model("Fingerbot MG90S");
    fingerbot = new DEV_Fingerbot();
}

void loop() {
  // Handles WiFi, mDNS discovery, pairing and all HomeKit traffic. Must be called
  // continuously — never put a long delay() in loop() here.
  homeSpan.poll();

  // Active low: internal pull-up holds the pin HIGH, pressing shorts it to GND.
  // Same Debouncer as Phase 1b/1c, proven on this hardware at 14 for 14.
  if (button.update(digitalRead(BUTTON_PIN) == LOW, millis())) {
    fingerbot->toggleFromButton();
  }
}

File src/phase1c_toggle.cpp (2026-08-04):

/*
  DIY Fingerbot — Phase 1c firmware (ESP32 + servo + button, two-position)
  ------------------------------------------------------------------------
  Adds exactly ONE new thing over Phase 1b: the arm now moves to TWO different
  angles depending on whether it's turning the switch on or off, and it remembers
  which state it last set.

  This is the shape the real thing needs. A wall rocker isn't a button — you press
  the top for ON and the bottom for OFF — so "press" was never enough. Phase 3
  swaps the button for HomeKit and otherwise looks like this.

    pio run -e phase1c_toggle -t upload

  Each button press flips the switch the other way. Watch the serial log: it
  reports the state it believes the switch is in after every move.

  Wiring is IDENTICAL to Phase 1b — no new parts, nothing to re-plug.
  See WIRING.md.

    servo signal (orange/yellow) -> GPIO 18
    servo V+     (red)           -> +5V of a SEPARATE 5V supply  (NOT the ESP32)
    servo GND    (brown/black)   -> GND of that supply
    ESP32 GND    ---------------- -> GND of that supply   (COMMON GROUND — required)
    button leg 1                 -> GPIO 4
    button leg 2                 -> ESP32 GND

  Do NOT run the servo off the ESP32's 5V/VIN pin. See the SERVO BROWNOUT note in
  project.md.
*/

#include <Arduino.h>
#include <ESP32Servo.h>
#include "debounce.h"
#include "switch_state.h"

Servo fingerArm;
const int SERVO_PIN  = 18;
const int BUTTON_PIN = 4;      // avoid strapping pins (0, 2, 12, 15) for inputs

// ---- Adjustable settings ----
// REST is where the arm lives between actuations: neutral, touching nothing, so
// it never holds the rocker down. ON and OFF sit either side of it.
//
// Which angle means "on" depends entirely on how you mount the servo relative to
// the switch. If the first real test turns things the wrong way round, swap these
// two numbers — that's the whole fix, no logic changes.
const int REST_ANGLE = 90;     // neutral, mid-travel
const int ON_ANGLE   = 60;     // swings one way
const int OFF_ANGLE  = 120;    // swings the other way

const int HOLD_MS = 500;       // how long to stay at the press angle
const unsigned long DEBOUNCE_MS = 50;

Debouncer  button(DEBOUNCE_MS);
SwitchState wallSwitch;        // assumes OFF at boot — see switch_state.h

// Move the arm to `angle`, hold, then return to neutral.
void actuate(int angle) {
  fingerArm.write(angle);
  delay(HOLD_MS);
  fingerArm.write(REST_ANGLE);
  delay(200);                  // let it settle before reporting
}

void setup() {
  Serial.begin(115200);

  pinMode(BUTTON_PIN, INPUT_PULLUP);

  // IMPORTANT: ESP32Servo needs its PWM timers allocated BEFORE attach(),
  // or the servo silently never moves. Do not remove these four lines.
  ESP32PWM::allocateTimer(0);
  ESP32PWM::allocateTimer(1);
  ESP32PWM::allocateTimer(2);
  ESP32PWM::allocateTimer(3);

  fingerArm.setPeriodHertz(50);            // standard 50 Hz servo
  fingerArm.attach(SERVO_PIN, 500, 2400);  // min/max pulse width (µs)
  fingerArm.write(REST_ANGLE);

  Serial.println("Fingerbot Phase 1c ready. Press the button to toggle.");
  Serial.println("Assuming the switch starts OFF.\n");
}

void loop() {
  // Active low: internal pull-up holds the pin HIGH, pressing shorts it to GND.
  bool pressed = (digitalRead(BUTTON_PIN) == LOW);

  if (button.update(pressed, millis())) {
    Action action = wallSwitch.toggle();

    switch (action) {
      case Action::TurnOn:
        Serial.println(">> Turning ON");
        actuate(ON_ANGLE);
        break;

      case Action::TurnOff:
        Serial.println(">> Turning OFF");
        actuate(OFF_ANGLE);
        break;

      case Action::None:
        // toggle() never returns this, but handle it so the compiler is happy
        // and so this switch stays correct when Phase 3 calls requestOn().
        Serial.println(">> Already in that state, not moving");
        break;
    }

    Serial.printf("   switch is now %s\n\n", wallSwitch.isOn() ? "ON" : "OFF");
  }
}

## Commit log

2026-08-02 Initial import: Fingerbot Phase 1 + 1b firmware
    ESP32 + MG90S servo that presses a physical wall switch. Two independently
    flashable PlatformIO environments:
    phase1_autopress - presses every 3s, no inputs. Known-good baseline.
    phase1b_button - presses on a debounced pushbutton (GPIO 4).
    Each env compiles exactly one source file via build_src_filter, so both can
    live in src/ without their setup()/loop() colliding. Phase 1 is preserved
    deliberately as a fallback for isolating hardware faults.
    Debounce logic is extracted to include/debounce.h, free of Arduino calls so
    it can be unit-tested on a host PC.
    Neither has been flashed - hardware is still in transit. Both compile clean
    for es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
    [phase1_autopress.cpp, phase1b_button.cpp]
2026-08-02 Add native unit tests for button debounce
    Eight Unity tests covering the debounce logic, run on the host PC with no
    ESP32 attached:
    pio test -e native
    Cases: idle, clean press, bouncing contacts, held button (no auto-repeat),
    release, press-release-press, sub-window glitch rejection, and millis()
    rollover after ~49 days.
    Verified non-vacuous by mutation: removing the debounce window from
    Debouncer::update() fails the glitch and bounce tests.
    Requires a native gcc; installed MinGW-w64 (WinLibs UCRT) for this.
2026-08-02 Add Wokwi simulation setup (ESP32 sim currently blocked)
    diagram.json models ESP32 + MG90S servo + pushbutton with contact bounce
    enabled, so the simulated firmware faces genuinely dirty edges. Passes
    wokwi-cli lint. Scenario asserts the full press sequence over serial.
    This would cover what the native unit tests cannot: ESP32Servo timer
    allocation, attach(), and the GPIO pull-up.
    It does not run yet. ESP32 simulations produce no serial and never execute.
    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
2026-08-02 Mirror firmware into workspace for the Wokwi VS Code extension
    The extension rejects any firmware path outside the workspace, reporting
    that the firmware binary was not found in workspace. That collides with
    workspace_dir, which deliberately points build output out of this
    OneDrive-synced folder.
    A post-build script now mirrors the artifacts into .wokwi/<env>/ and
    wokwi.toml uses a relative path into it. .wokwi/ is gitignored. The copy
    runs on every build rather than once, because stale firmware in a
    simulator fails silently -- you would be debugging yesterday's binary
    with nothing to tell you.
    Does not fix wokwi-cli, which is still silent for ESP32. Path containment
    had already been ruled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
2026-08-02 Add BOM with power specs, brownout parts, and switch measurements needed
2026-08-03 Add battery analysis: WiFi idle current rules out cells for permanent install
2026-08-03 Localise BOM to India: one link per item, prices, and totals
2026-08-04 Correct battery analysis: WiFi light sleep makes portable viable; add portable power options
2026-08-04 Record switchboard measurements; document rocker two-press-point constraint
2026-08-04 Correct rocker solution to push-pull tether; add SwitchBot benchmarks and arm length math
2026-08-04 Consolidate BOM to a single Robu.in order; add ESP32 and core parts
2026-08-04 Add single order-now checklist at top of BOM
2026-08-04 Add out-of-stock alternates with antenna and barrel-size warnings
2026-08-04 Add README and wiring/first-power-on checklist
2026-08-04 Record PCA9685 and small-board tradeoffs for the multi-gang build
2026-08-05 Add parametric OpenSCAD design for cradle, arm and rocker tab
    [arm20.stl, arm25.stl, arm30.stl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]
2026-08-05 Strengthen arm: limit horn slot length so the beam stays solid; add previews
    [arm20.stl, arm25.stl, arm30.stl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]
2026-08-05 Fix render.ps1: backslash-escape -D quotes and stop silent empty exports
    [arm20.stl, arm25.stl, arm30.stl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]
2026-08-05 Add reproducible arm underside preview; drop stale pre-fix render
    [arm20.stl, arm25.stl, arm30.stl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]
2026-08-05 Add Phase 1d: serial calibration console with tested command parser
2026-08-05 Document the calibration console in README, project brief and wiring guide
2026-08-11 Record first hardware validation: Phase 1 and Phase 1b run
    The servo physically presses. Phase 1 auto-presses on a 3s timer; Phase 1b
    fires on a GPIO 4 trigger. Serial timing matches the firmware to the tenth
    of a second, and the boot banner never reappeared across 22s of continuous
    pressing -- so the brownout this whole design was built around is not
    occurring with a 5V 2A supply and 1000uF near the servo. That was the
    project's biggest unknown and it is now closed.
    Phase 1b's GPIO input and debouncer are proven by tapping a jumper from
    pin 4 to GND: 8 taps, 8 presses, no double-fires. Tapping a bare wire
    bounces worse than any switch, so this is a harder test than the button.
    The physical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
2026-08-11 Phase 1b done on hardware: real pushbutton, 14 for 14
    The tactile switch now fires the servo. 14 pushes produced 14 presses with
    no double-fires -- and no two events landed closer than 0.9s, while contact
    bounce settles in single-digit milliseconds, so nothing spurious survived.
    DEBOUNCE_MS = 50 needs no tuning. include/debounce.h has now been proven
    twice on hardware: 8 jumper taps, then 14 real switch pushes.
    Drops the "switch not seated" caveat from STATUS.md, project.md and
    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
2026-08-11 Phase 1c validated on hardware: strict ON/OFF alternation
    Eight button presses under phase1c_toggle produced ON/OFF/ON/OFF/ON/OFF/
    ON/OFF with no repeats. Each move took exactly 0.7s from command to state
    report -- HOLD_MS 500 plus the 200ms settle in actuate() -- so the timing
    matches the firmware precisely.
    include/switch_state.h behaves on hardware as its 13 tests said it would.
    Combined with 1b's debouncer, every piece of logic written before the
    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
2026-08-11 Phase 3: Siri controls the servo
    "Hey Siri, turn on Fingerbot" swings the arm. HomeSpan makes the ESP32 a
    native HomeKit accessory -- no bridge, no hub, no subscription, no cloud
    account. Paired with Apple Home and driven by Siri on real hardware.
    The best result is in the serial log. Within 100 seconds of the first ever
    Siri session, HomeKit re-sent "turn on" while the switch was already ON,
    and SwitchState::requestOn() returned Action::None so the arm did not
    move. That is exactly the failure include/switch_state.h was written to
    prevent -- with a plain bool it would have pressed an already-on rocker
    and turned the light off. It was predicted in that file's header comment
    before any hardw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
    [phase3_homekit.cpp]
2026-08-11 Resolve the rocker dimensions: 20 x 40 mm
    Measured 2026-08-11. This supersedes the ~7 cm height that BOM.md has
    carried flagged as doubtful since 2026-08-04 -- that reading was spanning
    the whole faceplate, not one rocker, exactly as suspected.
    The 1:2 aspect ratio visible in the photos predicted ~4-4.5 cm, and 4 cm
    is what came back. It also reconciles with the Indian modular standard:
    nominally 22 x 45 mm, but that is the module including its bezel, and the
    visible rocker face sits inside it. Two independent sources now agree.
    Consequences, both good:
    - The rocker pivots at its centre, so each half is 20 x 20 mm. The
    adhesive tab in cad/fingerbot.scad is 14 x 10 mm, which fits inside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
2026-08-11 Phase 3: physical button works alongside Siri, and keeps Home in sync
    The button was dead weight after Phase 3 -- phase3_homekit.cpp never read
    GPIO 4. Now both trigger paths work, and more importantly they agree.
    The serial log caught the sequence that proves it. HomeKit turned the
    switch ON at t=102.1s; a button press at t=105.4s turned it OFF, not ON.
    So toggle() read the state Siri had just set. Both paths run through one
    SwitchState and one applyAction(), so they cannot drift apart in
    behaviour.
    The other direction matters just as much and is why setVal() is there.
    Press the button without telling HomeKit, and Apple Home keeps believing
    the old state -- so the next Siri command resolv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
    [phase3_homekit.cpp]
2026-08-11 Filament decided: PLA to test-fit, PETG for anything that stays
    Both are available, so the open question in STATUS.md is closed.
    Print #1 is a measuring tool, not a part. cad/fingerbot.scad says in its
    own header that the dimensions come from datasheets rather than the real
    servo, so the first print exists to reveal what is wrong with them. Use
    the cheap filament that prints easily and expect to bin it -- PLA also has
    slightly better dimensional accuracy than PETG, which is exactly what a
    fit check wants.
    PETG for the permanent parts, because PLA creeps under sustained load and
    softens in a warm room, and the cradle holds force against a wall for
    months.
    Print order changed to arm20 first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
2026-08-11 Correction: PETG throughout, including the test-fit prints
    Reverses the advice committed in 605217b, which said PLA for test-fitting
    and PETG for the final parts. That was self-defeating and the previous
    commit said so without noticing: PETG prints 0.1-0.3 mm larger than PLA at
    the same nominal size, which is the same order as the tolerances being
    checked. horn_blade_t is 1.9 mm and horn_hub_d is 7.4 mm, so a PLA fit
    does not predict a PETG fit and the test would simply have to be repeated.
    Printing the throwaway part in PETG has a second advantage that argues the
    same way: the PETG printer profile gets debugged on a part nobody cares
    about. Stringing, ooze and bed adhesion have to be solve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
2026-08-11 Add cad/PRINTING.md — spec sheet to hand to whoever prints the parts
    The printer belongs to a friend, so parts go out and come back in batches.
    That makes the round trip the expensive step, not the filament, and the
    instructions are written accordingly: print all three arm lengths in one
    go rather than picking one, because the right length is decided by testing
    against a real switch and not by looking at a screen. All three are about
    3 g each.
    Covers material (PETG, and what to say if only PLA is available), the
    settings that matter, and two things that are easy to get wrong:
    - Print the arms FLAT as oriented. The bending load then runs within the
    layers instead of across them. Stood u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
